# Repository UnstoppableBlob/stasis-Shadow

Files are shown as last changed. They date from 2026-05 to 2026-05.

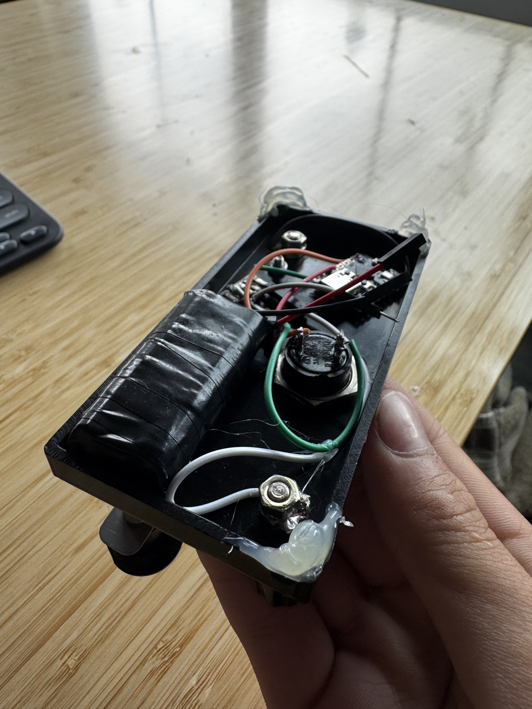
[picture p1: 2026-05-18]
corners/stasis photos/IMG_2151.JPG

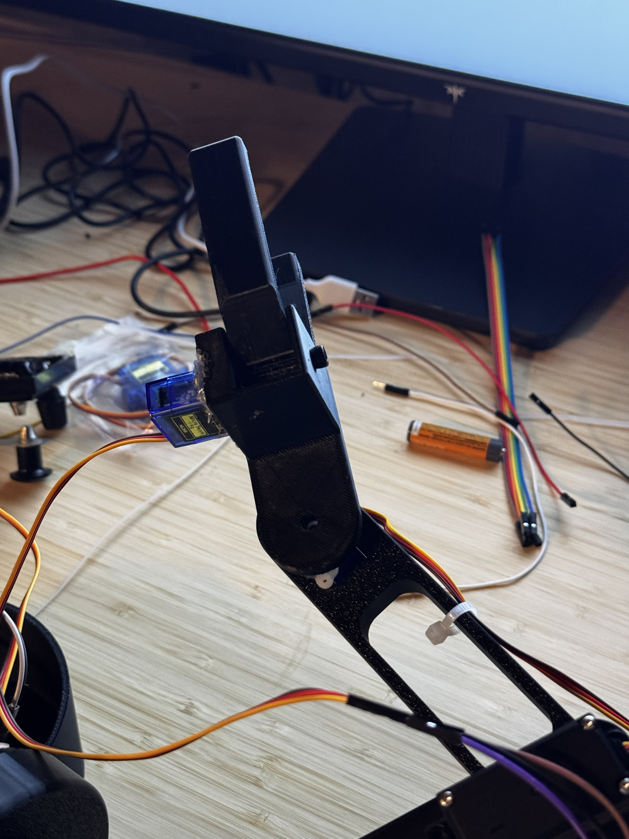
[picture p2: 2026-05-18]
corners/stasis photos/IMG_2200.JPG

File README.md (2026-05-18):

# Stasis Shadow

## What is it?

This is a robotic arm I made that uses servos, and has 5 axes! It's mainly controlled using a special glove with a gyroscope on it.

## How we made it

This is made using the MPU_Light library by rfetick, and also uses the WiFiUDP library from Arduino IDE. We also have a telegraph that is being used as a switch, and that controls the grabbing mechanism.

## How to Use it

You can use this by putting on the glove. If you want to rotate the arm, then you can make your index and thumb touch, and rotate either pitch or yaw. Yaw will move it left/right, and the pitch will increase/decrease distance away from base. Click the black button on the telegraph to open/close the grabber.

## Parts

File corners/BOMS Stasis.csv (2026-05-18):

 | Purpose | CAD | quantity
Robot Arm | Movement and grabbing | yes | 1
MG996R | Servo Motors | no | 3
ESP32-WROOM | MCU | no | 1
SG90 | Smaller Servo Motors | no | 2
Buck Converter | Step down voltage, increase amperage | no | 4
Telegraph | Morse Code | no | 1
ESP32 mini | MCU + UDP | no | 1
3 Volt Battery | Battery | no | 1
Glove | Housing all components | no | 1
ESP32 mini | MCU + UDP | no | 1
MPU6050 | Gyroscope + accelerometer | no | 1
3 Volt Battery | Battery | no | 1
Aluminum Pad | Capacitive touch | no | 2

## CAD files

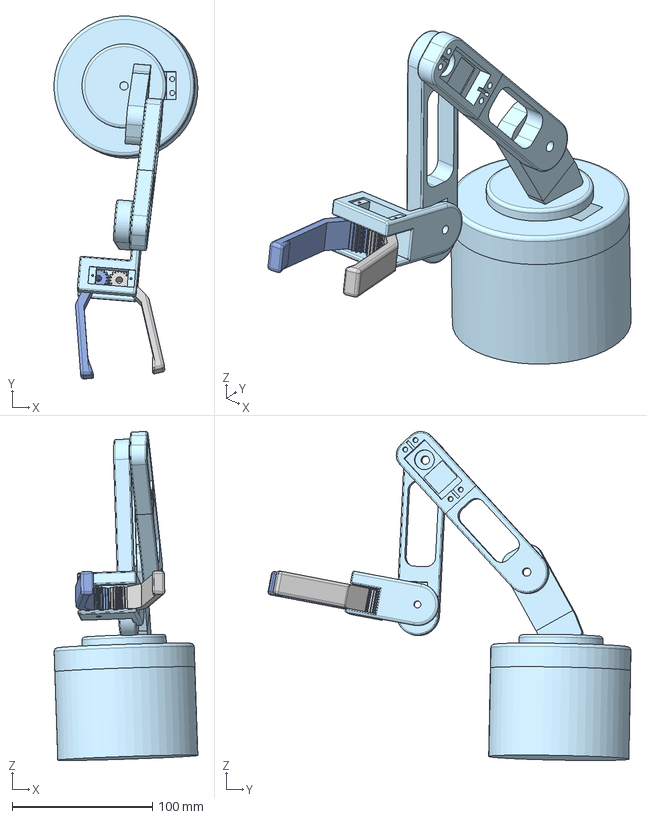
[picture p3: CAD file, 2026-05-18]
corners/CAD/Assembly 1.step
102.5 x 258.6 x 234.5 mm
RightClawArm
LeftClawArm
Claw

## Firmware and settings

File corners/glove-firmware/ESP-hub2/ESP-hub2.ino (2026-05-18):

#include <WiFi.h>
#include <WiFiUdp.h>
#include <ESP32Servo.h>

// --- Hotspot config ---
const char* AP_SSID     = "ESP32-Hub";
const char* AP_PASSWORD = "password123";
const int   UDP_PORT    = 4210;

// --- Servo pins ---
const int PIN_SHOULDER = 14;
const int PIN_ELBOW    = 25;
const int PIN_WRIST    = 26;
const int SERVO_PIN    = 13; // Base/Yaw
const int PIN_CLAW     = 27; // Added Claw Pin

// --- Claw Calibration ---
const int CLAW_OPEN_ANGLE  = 100; // Adjust if it opens too wide
const int CLAW_CLOSE_ANGLE = 0; // Adjust if it closes too hard

Servo servo1;
Servo servoShoulder, servoElbow, servoWrist, servoClaw;

// --- ARM DIMENSIONS ---
float arm1        = 110.0;
float arm2        = 102.5;
float totalLength = arm1 + arm2;

// --- CALIBRATION: tune these ---
bool  reverseElbow    = false;
bool  reverseShoulder = false;
bool  reverseWrist    = false;

float offsetElbow    = 75.0;
float offsetShoulder = 130.0;
float offsetWrist    = 0.0;

float distance = 0;
WiFiUDP udp;

struct SensorData {
  float yaw;
  float roll;
};

float clamp(float v) { return constrain (v, -1.0, 1.0); }

// --- TRIANGLE MATH ---
void getAngles(float pitch, int &angleElbow, int &angleShoulder, int &angleWrist) {
  pitch = constrain(pitch, 5.0, 85.0);

  float dist = ((pitch - 5.0) / (85.0 - 5.0)) * totalLength;
  dist = constrain(dist, 1.0, totalLength - 1.0);

  float inputElbow    = (arm1*arm1 + arm2*arm2 - dist*dist) / (2.0 * arm1 * arm2);
  float inputShoulder = (arm1*arm1 + dist*dist - arm2*arm2) / (2.0 * arm1 * dist);

  Serial.print("acos inputs — Elbow: "); Serial.print(inputElbow);
  Serial.print("  Shoulder: ");          Serial.println(inputShoulder);

  float rawElbow    = acos(clamp(inputElbow))    * 180.0 / M_PI;
  float rawShoulder = acos(clamp(inputShoulder)) * 180.0 / M_PI;
  float rawWrist    = 180.0 - rawShoulder - rawElbow;

  Serial.print("RAW — Elbow: ");    Serial.print(rawElbow);
  Serial.print("  Shoulder: ");     Serial.print(rawShoulder);
  Serial.print("  Wrist: ");        Serial.println(rawWrist);

  angleElbow    = constrain((reverseElbow    ? 180.0 - rawElbow    : rawElbow)    + offsetElbow,    0, 180);
  angleShoulder = constrain((reverseShoulder ? 180.0 - rawShoulder : rawShoulder) + offsetShoulder, 0, 180);
  angleWrist    = constrain((reverseWrist    ? 180.0 - rawWrist    : rawWrist)    + offsetWrist,    0, 180);
}

void setup() {
  Serial.begin(115200);
  delay(2000);
  Serial.println("BOOTING...");

  // Allocate hardware timers for ESP32 PWM channels
  ESP32PWM::allocateTimer(0);
  ESP32PWM::allocateTimer(1);
  ESP32PWM::allocateTimer(2);
  ESP32PWM::allocateTimer(3);

  servo1.setPeriodHertz(50);
  servo1.attach(SERVO_PIN, 600, 2300);
  servoShoulder.attach(PIN_SHOULDER);
  servoElbow.attach(PIN_ELBOW);
  servoWrist.attach(PIN_WRIST);
  
  // Setup the new Claw Servo
  servoClaw.setPeriodHertz(50);
  servoClaw.attach(PIN_CLAW, 500, 2400);

  // Initialize to pitch=5 (all the way in)
  int initElbow, initShoulder, initWrist;
  getAngles(45, initElbow, initShoulder, initWrist);

  servo1.write(90);
  servoElbow.write(initElbow);
  servoShoulder.write(initShoulder);
  servoWrist.write(initWrist);
  servoClaw.write(CLAW_OPEN_ANGLE); // Start with the claw open!

  Serial.print("Init — Elbow: ");    Serial.print(initElbow);
  Serial.print("  Shoulder: ");      Serial.print(initShoulder);
  Serial.print("  Wrist: ");         Serial.println(initWrist);

  delay(500);

  WiFi.softAP(AP_SSID, AP_PASSWORD, 6, 0, 4);
  Serial.print("Hotspot started. IP: ");
  Serial.println(WiFi.softAPIP());
  udp.begin(UDP_PORT);
  Serial.println("Listening on UDP port 4210...");
}

void loop() {
  int packetSize = udp.parsePacket();

  // --- Route 1 for the 8-byte MPU Data ---
  if (packetSize == sizeof(SensorData)) {
    SensorData receivedData;
    udp.read((char*)&receivedData, sizeof(receivedData));

    float valX = receivedData.yaw;
    float valZ = receivedData.roll;

    valX = constrain(valX, -90.0, 90.0);
    valZ = constrain(valZ, 15.0, 65.0);

    // Yaw → servo1
    int servoAngleX = (int)(valX + 90.0);
    servo1.write(servoAngleX);

    // Pitch → triangle servos
    int angleElbow, angleShoulder, angleWrist;
    getAngles(valZ, angleElbow, angleShoulder, angleWrist);

    servoElbow.write(angleElbow);
    servoShoulder.write(angleShoulder);
    servoWrist.write(angleWrist);

    Serial.print("Yaw: ");       Serial.print(valX, 1);
    Serial.print(" Servo1: ");   Serial.print(servoAngleX);
    Serial.print(" | Pitch: ");  Serial.print(valZ, 1);
    Serial.print(" Raw Pitch: "); Serial.print(receivedData.roll);
    Serial.print(" Elbow: ");    Serial.print(angleElbow);
    Serial.print(" Shoulder: "); Serial.print(angleShoulder);
    Serial.print(" Wrist: ");    Serial.println(angleWrist);

  } 
  // --- Route 2 for the 1-byte C3 Tapper Data ---
  else if (packetSize == sizeof(uint8_t)) {
    uint8_t tapperState;
    udp.read((char*)&tapperState, sizeof(tapperState));
    
    if (tapperState == 1) {
      Serial.println("TAPPER: Pinched! Closing claw.");
      servoClaw.write(CLAW_CLOSE_ANGLE); // Snap shut
    } else {
      Serial.println("TAPPER: Released! Opening claw.");
      servoClaw.write(CLAW_OPEN_ANGLE);  // Snap open
    }
    
  } 
  // Clear out junk packets
  else if (packetSize > 0) {
    udp.flush();
  }
}

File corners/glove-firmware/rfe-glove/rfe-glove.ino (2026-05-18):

#include "I2Cdev.h"
#include "MPU6050_6Axis_MotionApps20.h"
#if I2CDEV_IMPLEMENTATION == I2CDEV_ARDUINO_WIRE
#include "Wire.h"
#endif
#include <WiFi.h>
#include <WiFiUdp.h>

// --- WiFi / UDP config ---
const char* AP_SSID     = "ESP32-Hub";
const char* AP_PASSWORD = "password123";
const char* WROOM_IP    = "192.168.4.1";
const int   UDP_PORT    = 4210;

WiFiUDP udp;

// --- MPU ---
MPU6050 mpu;

const int BUTTON_PIN = 21;

bool DMPReady = false;
uint8_t devStatus;
uint16_t packetSize;
uint8_t FIFOBuffer[64];

Quaternion q;
VectorFloat gravity;
float ypr[3];

float yawOffset = 0, rollOffset = 0;
bool wasPinching = false;
unsigned long lastPrintTime = 0;

// --- ADDED: The High-Speed Binary Data Structure ---
struct SensorData {
  float yaw;
  float roll;
};

void setup() {
  Wire.begin(8, 9);
  Wire.setClock(400000);
  pinMode(BUTTON_PIN, INPUT_PULLUP);
  Serial.begin(115200);
  while (!Serial);

  // --- WiFi ---
  WiFi.begin(AP_SSID, AP_PASSWORD);
  Serial.print("Connecting to ESP32-Hub");
  while (WiFi.status() != WL_CONNECTED) {
    delay(500);
    Serial.print(".");
  }
  Serial.println();
  Serial.print("Connected! IP: ");
  Serial.println(WiFi.localIP());
  udp.begin(4212);

  // --- MPU ---
  mpu.initialize();
  if (!mpu.testConnection()) {
    Serial.println("MPU6050 connection failed!");
    while (true);
  }


  devStatus = mpu.dmpInitialize();
  mpu.setXGyroOffset(0);
  mpu.setYGyroOffset(0);
  mpu.setZGyroOffset(0);
  mpu.setXAccelOffset(0);
  mpu.setYAccelOffset(0);
  mpu.setZAccelOffset(0);

  if (devStatus == 0) {
    mpu.CalibrateAccel(6);
    mpu.CalibrateGyro(6);
    mpu.setDMPEnabled(true);
    DMPReady = true;
    packetSize = mpu.dmpGetFIFOPacketSize();
    Serial.println("MPU ready.");
  } else {
    Serial.print("DMP failed, code: ");
    Serial.println(devStatus);
  } 
}

void loop() {
  if (!DMPReady) return;

  // --- WiFi watchdog ---
  if (WiFi.status() != WL_CONNECTED) {
    WiFi.begin(AP_SSID, AP_PASSWORD);
    while (WiFi.status() != WL_CONNECTED) delay(500);
  }

  if (!mpu.dmpGetCurrentFIFOPacket(FIFOBuffer)) return;

  mpu.dmpGetQuaternion(&q, FIFOBuffer);
  mpu.dmpGetGravity(&gravity, &q);
  mpu.dmpGetYawPitchRoll(ypr, &q, &gravity);

  float yaw  = ypr[0] * 180.0 / M_PI;
  float roll = ypr[2] * 180.0 / M_PI;

  bool isPinching = (digitalRead(BUTTON_PIN) == LOW);

  if (isPinching) {
    if (!wasPinching) {
      // Tare on first pinch frame
      float sumY = 0, sumR = 0;
      for (int i = 0; i < 20; i++) {
        while (!mpu.dmpGetCurrentFIFOPacket(FIFOBuffer));
        mpu.dmpGetQuaternion(&q, FIFOBuffer);
        mpu.dmpGetGravity(&gravity, &q);
        mpu.dmpGetYawPitchRoll(ypr, &q, &gravity);
        sumY += ypr[0] * 180.0 / M_PI;
        sumR += ypr[2] * 180.0 / M_PI;
        delay(10);
      }
      yawOffset  = sumY / 20.0;
      rollOffset = sumR / 20.0;

      wasPinching = true;
      lastPrintTime = millis();
    }

    if (millis() - lastPrintTime >= 50) {
      float relYaw  = yaw  - yawOffset;
      float relRoll = roll - rollOffset;

      if (relYaw >  180) relYaw -= 360;
      if (relYaw < -180) relYaw += 360;

      relYaw = -relYaw;


      // 1. Create the struct and load it with your data
      SensorData myData;
      myData.yaw = relYaw;
      myData.roll = relRoll;

      // 2. Send the raw binary packet (No strings attached!)
      udp.beginPacket(WROOM_IP, UDP_PORT);
      udp.write((uint8_t*)&myData, sizeof(myData));
      udp.endPacket();

  Serial.print("Sent X: ");
  Serial.print(myData.yaw);
  Serial.print("\tZ: ");
  Serial.println(myData.roll); // mirror to serial for debugging

      lastPrintTime = millis();
    }

  } else {
    wasPinching = false;
  }
}

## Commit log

2026-05-18 add bom
    [BOMS Stasis.csv]
2026-05-18 add cad
    [Assembly 1.step]
